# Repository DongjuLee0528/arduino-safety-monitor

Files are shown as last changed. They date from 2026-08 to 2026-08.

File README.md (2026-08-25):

# Invent the Future with Arduino UNO Q and App Lab: Mobile Safety Monitoring Robot

A mobile Arduino UNO Q robot that combines autonomous obstacle avoidance with App Lab helmet-compliance monitoring.

## Project Overview

This project was built for the "Invent the Future with Arduino UNO Q and App Lab" competition. It explores a mobile safety-monitoring robot that can patrol a workspace, avoid nearby obstacles, detect people with a camera, classify whether a detected person is wearing a safety helmet, and show the system state in an Arduino App Lab dashboard.

The repository contains Arduino MCU firmware, a Python MPU runtime, an App Lab dashboard package generator, AI training and evaluation code, model artifacts, tests, wiring documentation, robot photographs, and demonstration media.

This is an independently developed project. Hardware details that have not yet been confirmed are marked instead of being guessed.

## Problem Statement

Fixed safety cameras only observe selected areas. A mobile robot can inspect additional viewpoints while carrying its own camera, obstacle sensors, and local control logic. This prototype combines autonomous navigation with helmet-compliance monitoring.

This project is a functional prototype and is not an industrially certified safety device.

## Project Goals

- Build a physical Arduino UNO Q robot platform.
- Keep MCU responsibilities focused on motor control, ultrasonic sensing, motion authorization, and local warning outputs.
- Keep MPU responsibilities focused on camera input, AI inference, dashboard state, App Lab integration, and alert transmission.
- Use Arduino App Lab Bridge IPC for MCU-MPU commands.
- Detect people, crop each person, and classify helmet status.
- Provide clear dashboard evidence for helmet and no-helmet states.
- Stop or restrict motion on communication loss, stale motion lease, manual-hold timeout, and explicit reset.

## Key Features

| Feature | Evidence | Status |
|---|---|---|
| App Lab Bridge RPC communication | `mpu/bridge_rpc.py`, `arduino/arduino.ino`, `arduino/comm.h` | Implemented in code |
| MCU motor control through L298N | `arduino/motor.h`, `arduino/pins.h` | Implemented in firmware |
| Four HC-SR04 ultrasonic sensors | `arduino/ultrasonic.h`, `arduino/pins.h` | Implemented in firmware |
| Autonomous obstacle-avoidance state machine | `arduino/navigation.h`, `arduino/robot_controller.h` | Implemented and demonstrated separately |
| Helmet/no-helmet AI pipeline | `mpu/main.py`, `mpu/detector.py`, `mpu/classifier.py` | Implemented in Python runtime |
| App Lab dashboard | `app_lab/ui/assets/index.html`, `app_lab/generate_app_lab.py` | Implemented and packaged |
| Dashboard statistics and event log | `mpu/dashboard_state.py`, dashboard screenshots | Implemented in software |
| LED warning output on D3 | `arduino/pins.h`, `arduino/comm.h` | Implemented in firmware |
| Buzzer diagnostic output on D13 | `arduino/pins.h`, `arduino/comm.h` | Implemented in firmware |

## Innovation and Differentiation

The project combines mobile monitoring and personal protective equipment detection in one small prototype. Instead of relying only on fixed cameras, the robot can move through a space while the MPU performs person detection and helmet classification.

The MCU remains responsible for time-sensitive motion, sensor processing, and safety behaviour, while the MPU handles AI inference, dashboard state, camera processing, and alert logic.

The communication design separates general connectivity from motion authorization. A connectivity check alone does not authorize continued movement. Motion authority is maintained through control and manual-hold updates, reducing the risk of stale commands continuing after communication problems.

## System Architecture

```mermaid
flowchart LR
    Camera[USB camera] --> MPU[Python MPU runtime]
    MPU --> Detector[MobileNet SSD person detector]
    Detector --> Crop[Person crop]
    Crop --> Classifier[ONNX helmet classifier]
    Classifier --> Dashboard[App Lab dashboard state]
    Classifier --> Alert[Alert manager and HTTP sender]
    Dashboard --> AppUI[App Lab Web UI]
    AppUI --> Bridge[Arduino App Lab Bridge.call]
    MPU --> Bridge
    Bridge --> MCU[Arduino UNO Q MCU firmware]
    MCU --> Nav[Navigation manager]
    MCU --> Motors[L298N motor driver and TT motors]
    Sensors[HC-SR04 ultrasonic sensors] --> MCU
    MCU --> LocalAlert[D3 LED and D13 buzzer outputs]
```

The active MCU-MPU communication path is Arduino UNO Q App Lab Bridge IPC using named RPC endpoints such as:

- `asm_motor`
- `asm_mode`
- `asm_status`
- `asm_safe_reset`

The current implementation does not use raw USB Serial JSON-RPC as its production transport.

## End-to-End Operation Flow

1. The App Lab package starts the Python adapter generated by `app_lab/generate_app_lab.py`.
2. The adapter validates the runtime model files and starts `HelmetDetectionSystem`.
3. The Python runtime opens the camera and connects to the MCU through `Bridge.call`.
4. Each camera frame is processed by `PersonDetector`.
5. Each detected person is cropped and passed to `HelmetClassifier`.
6. The dashboard state is updated with worker presence, helmet result, confidence, statistics, and recent events.
7. For a no-helmet incident, the alert manager can request the MCU warning output and send an HTTP alert.
8. The dashboard polls `/api/state` and `/api/frame` to display the live system state and camera frame.
9. The MCU executes autonomous or manual motor behaviour and reports status through `asm_status`.
10. `safe_reset`, motion lease timeout, manual-hold timeout, and communication timeout stop or restrict movement.

## Implementation Status

| Area | Status | Notes |
|---|---|---|
| Physical robot | Built | Supported by robot photographs |
| Circuit diagram | Documented | `docs/images/circuit-image.svg` |
| MCU firmware | Implemented | Arduino RouterBridge/RPClite endpoints are registered |
| Python MPU runtime | Implemented | Integrates the camera, detector, classifier, Bridge, sender, and dashboard |
| App Lab dashboard | Implemented | HTML/CSS/JavaScript dashboard and generated package included |
| Autonomous navigation | Implemented | Demonstrated in a separate video |
| Helmet dashboard state | Implemented | Demonstrated through dashboard screenshots |
| LED and buzzer outputs | Firmware implemented | Physical verification evidence is limited |
| Continuous end-to-end demonstration | Not documented | Navigation and helmet monitoring were demonstrated separately |

## Hardware Overview

The robot uses a four-wheel chassis with an Arduino UNO Q, L298N motor driver, four TT geared motors, four HC-SR04 ultrasonic sensors, a Logitech C922 Pro HD Stream Webcam, and custom 3D-printed mechanical parts.

The power system uses a TERANTY 2S LiPo battery, an XL6009 DC-DC boost converter configured to 18 V, an Aideepen USB-C PD output module, and a DSEOM USB-C 7-in-1 multi-hub.

The Arduino UNO Q and Logitech C922 camera are connected through the USB-C hub.

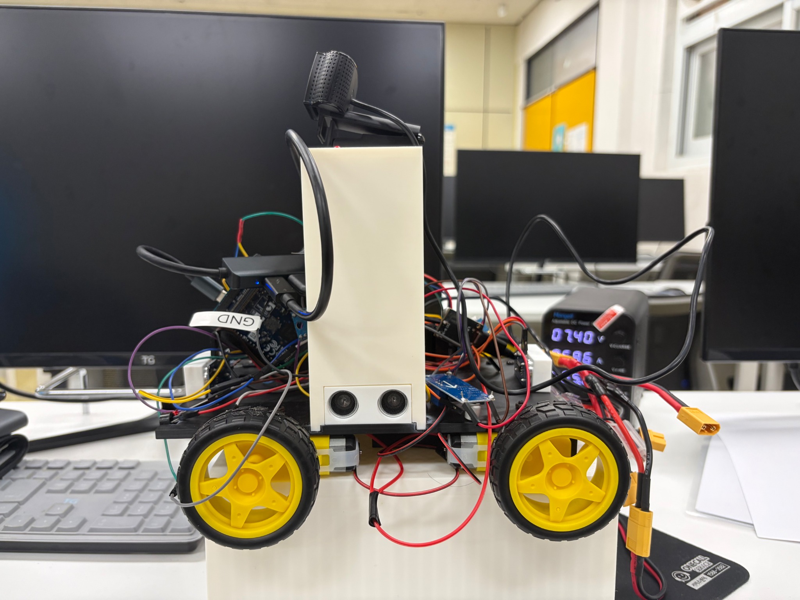
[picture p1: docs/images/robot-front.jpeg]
Front view of the completed robot


The front photograph shows the completed robot with the front ultrasonic sensor assembly and upper electronics area.

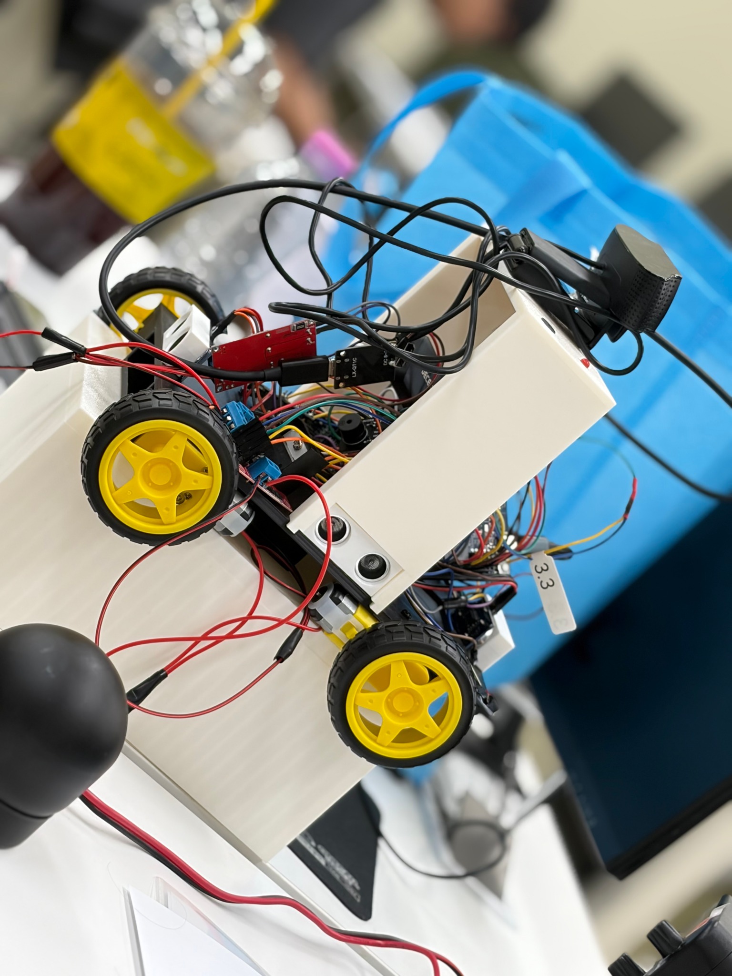
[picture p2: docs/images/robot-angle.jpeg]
Angled view of the completed robot


The angled photograph shows the chassis, wheels, wiring, controller area, and camera mount.

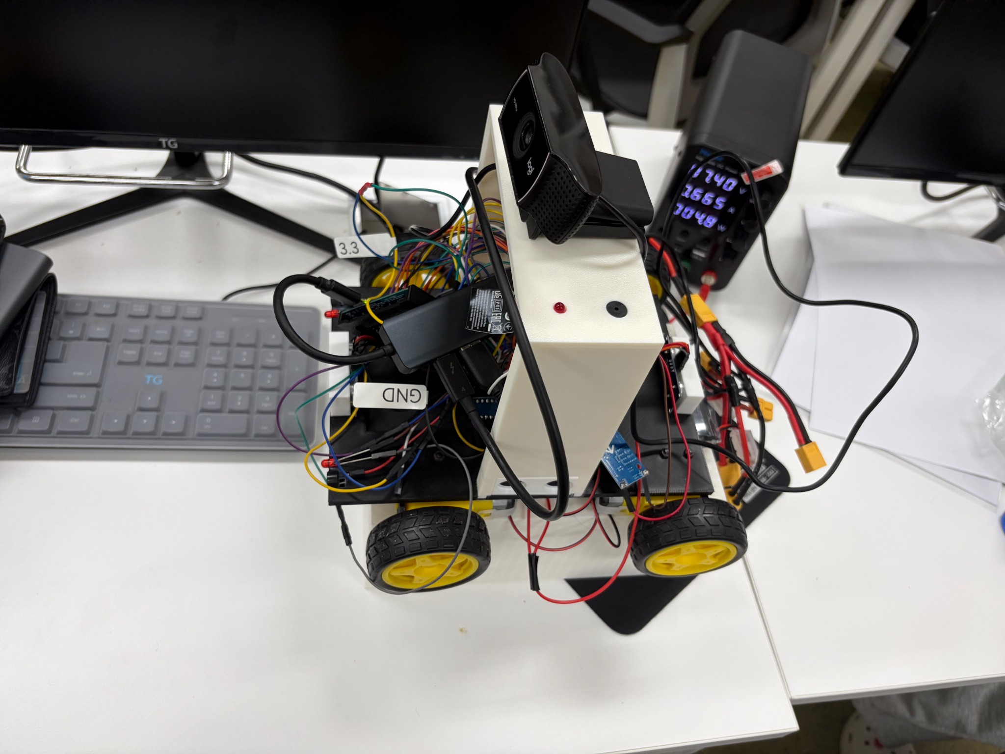
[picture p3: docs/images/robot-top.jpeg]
Top view of the completed robot


The top photograph shows the controller and wiring arrangement.

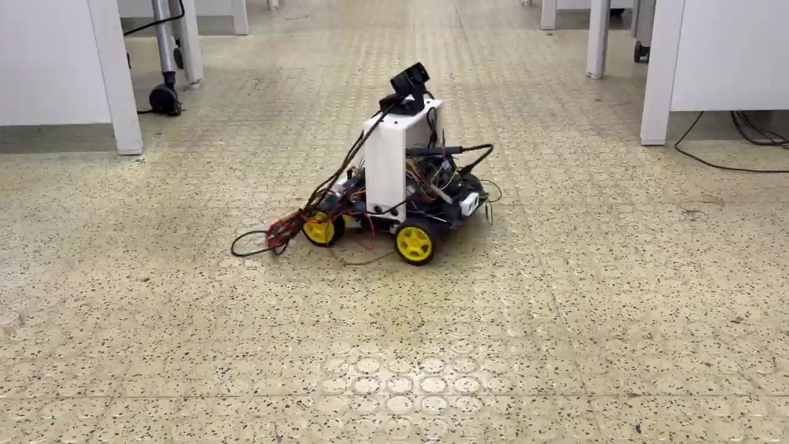
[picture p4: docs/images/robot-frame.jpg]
Robot frame before final assembly


The frame photograph shows the custom base structure before the final upper assembly was installed.

## Complete Hardware BOM

| Component | Model or Specification | Quantity | Purpose | Status |
|---|---|---:|---|---|
| Controller board | Arduino UNO Q | 1 | MCU firmware, App Lab Bridge, and robot control | Implemented |
| Motor driver | L298N dual H-bridge | 1 | Controls the left and right motor groups | Implemented |
| DC geared motors | TT geared motor | 4 | Four-wheel drive | Implemented |
| Wheels | TT motor-compatible wheel | 4 | Robot locomotion | Implemented |
| Ultrasonic sensors | HC-SR04 | 4 | Front, rear, left, and right obstacle sensing | Implemented |
| Camera | Logitech C922 Pro HD Stream Webcam | 1 | Person detection and helmet classification | Implemented |
| Logic-level shifter | TXS0108E | 1 | 5 V and 3.3 V logic-level conversion | Implemented |
| Battery | TERANTY 2S LiPo, 7.4 V nominal, 2,200 mAh, 50C, XT60 | 1 | Main robot power source | Implemented |
| Boost converter | XL6009 adjustable DC-DC boost converter | 1 | Raises the battery voltage to 18 V | Implemented |
| USB-C PD output module | Aideepen 45 W model, DC 8–30 V input, PD/QC3.0/SCP/PPS | 1 | Generates USB-C PD output from the boosted supply | Implemented |
| USB-C multiport hub | DSEOM USB-C 7-in-1 multi-hub | 1 | Connects and powers the Arduino UNO Q and USB camera | Implemented |
| Alert LED | Red LED connected to D3 | 1 | Local visual warning | Firmware implemented |
| Buzzer | Buzzer connected to D13 | 1 | Local audible warning or diagnostic output | Firmware implemented |
| Jumper wires and connectors | Signal and power wiring | 1 set | Electrical connections | Implemented |
| M3 × 8 mm bolts | M3, 8 mm length | 8 | Component and bracket fastening | Implemented |
| M3 × 25 mm bolts | M3, 25 mm length | 8 | Chassis and structural fastening | Implemented |
| M3 nuts | Standard M3 nuts | 16 | Fastens the M3 bolts | Implemented |
| Custom 3D-printed parts | Chassis, base plate, sensor mounts, camera mount, and electronics mounts | 1 set | Mechanical structure and component mounting | Designed by Dongju Lee |
| TT motor brackets | [TT Gear Motor Mount](https://makerworld.com/en/models/519327-tt-gear-motor-mount) by [Chief human](https://makerworld.com/en/@Chief_human) | 4 | Mounts the four TT motors | Used with creator permission and licensed under [CC BY 4.0](https://creativecommons.org/licenses/by/4.0/) |

## Software and Development Tools

| Tool or Library | Evidence | Purpose |
|---|---|---|
| Arduino and C++ | `arduino/*.ino`, `arduino/*.h` | MCU firmware |
| Arduino App Lab | `app_lab/generate_app_lab.py`, generated App Lab package | Packaging and dashboard runtime |
| Python | `mpu/*.py`, `mpu/ai/*.py` | MPU runtime, AI training, and tests |
| JavaScript, HTML, and CSS | `app_lab/ui/assets/index.html` | Dashboard UI |
| OpenCV | `requirements.txt`, `mpu/camera.py`, `mpu/detector.py` | Camera capture and image processing |
| ONNX Runtime | `requirements.txt`, `mpu/detector.py`, `mpu/classifier.py` | Runtime AI inference |
| PyTorch and torchvision | `requirements.txt`, `mpu/ai/train.py` | AI model training |
| ONNX | `requirements.txt`, `mpu/ai/convert.py` | Model conversion and validation |
| Pillow | `requirements.txt`, `mpu/classifier.py` | Image preprocessing |
| requests | `requirements.txt`, `mpu/sender.py` | HTTP alert transmission |
| unittest and pytest-compatible tests | `mpu/tests/`, `tests/`, `setup.cfg` | Automated software testing |
| 3D modelling tools | `models/*.stl`, `models/*.3mf` | Mechanical design assets |

## Circuit Diagram and Power Architecture

Circuit diagram for the Arduino UNO Q safety monitoring robot

The circuit diagram documents the Arduino UNO Q, L298N motor driver, four HC-SR04 sensors, D3 LED output, and D13 buzzer output.

The verified system power flow is:

```text
TERANTY 2S LiPo Battery
7.4 V nominal / 2,200 mAh / 50C / XT60
              |
              v
XL6009 DC-DC Boost Converter
Output configured to 18 V
              |
              v
Aideepen 45 W USB-C PD Output Module
              |
              v
DSEOM USB-C 7-in-1 Multi-hub
              |
              +-- Arduino UNO Q
              |
              `-- Logitech C922 Pro HD Stream Webcam
```

The XL6009 is used only as a DC-DC boost converter. USB Power Delivery output is handled by the separate Aideepen USB-C PD module.

The 18 V value applies to the XL6009 output supplied to the USB-C PD module. It does not mean that every downstream device directly receives 18 V. The USB-C PD module and connected devices negotiate or regulate their downstream voltage.

The Aideepen module supports up to 45 W, but this does not mean that the complete system continuously supplies 45 W. Actual available power is limited by the XL6009 converter, battery voltage, wiring, thermal conditions, and negotiated USB-C PD profile.

### Electrical Notes

- L298N ENA and ENB are driven by PWM pins D5 and D6.
- L298N direction pins use D2, D4, D7, and D8.
- Four HC-SR04 sensors use D9/D10, D11/D12, A0/A1, and A2/A3.
- The Arduino UNO Q, L298N, battery circuit, and sensors must use a common ground.
- HC-SR04 sensors are powered through the 5 V bus.
- The XL6009 output must be measured before downstream devices are connected.

### Software Safety Behaviour

- The MCU stops motion when the motion lease expires.
- The MCU switches to manual mode and queues a stop when `safe_reset` is executed.
- Missing or stale ultrasonic readings are treated as blocked.
- Manual movement requires continuing hold or lease refreshes.
- Communication loss prevents stale motion commands from continuing indefinitely.

## Pin Map

| Function | Arduino Pin | Firmware Constant |
|---|---|---|
| L298N ENA, left PWM | D5 | `MOTOR_LEFT_ENABLE_PIN` |
| L298N IN1, left direction A | D2 | `MOTOR_LEFT_IN1_PIN` |
| L298N IN2, left direction B | D4 | `MOTOR_LEFT_IN2_PIN` |
| L298N ENB, right PWM | D6 | `MOTOR_RIGHT_ENABLE_PIN` |
| L298N IN3, right direction A | D7 | `MOTOR_RIGHT_IN1_PIN` |
| L298N IN4, right direction B | D8 | `MOTOR_RIGHT_IN2_PIN` |
| Alert LED | D3 | `ALERT_LED_PIN` |
| Buzzer diagnostic output | D13 | `BUZZER_DIAG_PIN` |
| Front HC-SR04 trigger | D9 | `ULTRASONIC_FRONT_TRIGGER_PIN` |
| Front HC-SR04 echo | D10 | `ULTRASONIC_FRONT_ECHO_PIN` |
| Rear HC-SR04 trigger | D11 | `ULTRASONIC_REAR_TRIGGER_PIN` |
| Rear HC-SR04 echo | D12 | `ULTRASONIC_REAR_ECHO_PIN` |
| Left HC-SR04 trigger | A0 | `ULTRASONIC_LEFT_TRIGGER_PIN` |
| Left HC-SR04 echo | A1 | `ULTRASONIC_LEFT_ECHO_PIN` |
| Right HC-SR04 trigger | A2 | `ULTRASONIC_RIGHT_TRIGGER_PIN` |
| Right HC-SR04 echo | A3 | `ULTRASONIC_RIGHT_ECHO_PIN` |

The following pins are reserved by `arduino/pins.h`:

| Pin | Purpose |
|---|---|
| D0 | UART RX |
| D1 | UART TX |
| A4 | I2C SDA |
| A5 | I2C SCL |

## Hardware Assembly Guide

1. Print or prepare the custom chassis components from the files in `models/`.
2. Print four TT motor brackets using the credited third-party model.
3. Mount the four TT geared motors using the TT motor brackets.
4. Attach the four wheels to the motors.
5. Assemble the structural components using the M3 bolts and nuts.
6. Mount the Arduino UNO Q and L298N motor driver.
7. Install the four HC-SR04 sensors for front, rear, left, and right coverage.
8. Mount the Logitech C922 camera.
9. Wire the L298N motor driver according to the pin map.
10. Connect the TERANTY 2S LiPo battery to the XL6009 input.
11. Disconnect the Arduino UNO Q, USB-C hub, camera, and PD module before adjusting the XL6009.
12. Adjust the XL6009 output and confirm 18 V using a multimeter.
13. Connect the XL6009 output to the Aideepen USB-C PD module.
14. Connect the Aideepen module to the DSEOM multi-hub PD input.
15. Connect the Arduino UNO Q and Logitech C922 camera to the DSEOM hub.
16. Verify polarity, common ground, converter output, and motor/logic power separation.
17. Connect power only after completing all electrical checks.

Do not execute motor or diagnostic commands until the robot is physically supported, the wheels are clear, and the power wiring has been checked.

## AI Pipeline

The runtime AI flow is:

1. `CameraCapture` captures a BGR frame from camera index `0`.
2. `PersonDetector` loads `mpu/ai/models/ssd_mobilenet_v1_12.onnx`.
3. The detector filters COCO class ID `1` for person detections with a confidence of at least `0.5`.
4. `HelmetDetectionSystem.crop_person()` crops each detected person.
5. `HelmetClassifier` loads `mpu/ai/models/best_model.onnx`.
6. The classifier resizes each crop to `224 × 224`.
7. ImageNet normalization is applied.
8. ONNX Runtime performs helmet classification.
9. Output index `0` represents `no_helmet`.
10. Output index `1` represents `helmet`.
11. The runtime predicts `helmet` only when `P(helmet) >= 0.83`.
12. The dashboard receives the result, confidence, bounding box, statistics, and event updates.

The training loader uses per-object crops from annotated source images. This matches the runtime classifier input more closely than full-frame training.

## Datasets and Data Preparation

The training code uses the SHEL5K dataset path configured in `mpu/config.py`:

```text
~/AIdatasets/helmet-safety-robot/raw/9rcv8mm682-4/Safety Helmet Wearing Dataset
```

The expected dataset structure is:

```text
Safety Helmet Wearing Dataset/
+-- Annotations/
`-- Images/
```

The following Pascal VOC object labels are used:

| Annotation Label | Class Index | Runtime Class |
|---|---:|---|
| `person_no_helmet` | 0 | `no_helmet` |
| `person_with_helmet` | 1 | `helmet` |

Head-only and helmet-only labels are excluded because they do not match the runtime whole-person crop contract.

SHWD is present in configuration as `SHWD_PATH`, but it is excluded from the current baseline training process.

## Training Process

Run the training process with:

```bash
python -m mpu.ai.train \
  --architecture efficientnet_b0 \
  --epochs 30 \
  --batch-size 32 \
  --lr 0.001 \
  --seed 42 \
  --patience 5 \
  --train-ratio 0.8 \
  --output-dir mpu/ai/runs
```

Training artifacts are written under:

```text
mpu/ai/runs/<run_id>/
```

The training script protects production model files in `mpu/ai/models/` from being overwritten.

Supported classifier architectures:

- EfficientNet-B0
- MobileNetV3-Small
- MobileNetV3-Large

Training uses:

- ImageNet pretrained weights
- Adam optimizer
- Weighted `CrossEntropyLoss`
- Source-image-grouped train/validation splitting
- Early stopping based on validation loss
- Fixed random seed for reproducibility

## Model Comparison and Selection

The repository includes comparison artifacts under:

```text
mpu/ai/comparisons/four_model_comparison/
```

The selected production candidate is:

```text
20260820_204342_efficientnet_b0
```

This model uses EfficientNet-B0 with a learning rate of `0.0003`.

| Run | Architecture | Learning Rate | Validation Accuracy | Macro F1 | No-Helmet Recall | Missed Violations | False Alarms | ONNX Size |
|---|---|---:|---:|---:|---:|---:|---:|---:|
| `20260820_171048_efficientnet_b0` | EfficientNet-B0 | 0.001 | 93.6136% | 0.9177 | 0.9342 | 50 | 146 | 15.978 MB |
| `20260820_193048_mobilenet_v3_small` | MobileNetV3-Small | 0.001 | 93.7113% | 0.9170 | 0.8987 | 77 | 116 | 6.157 MB |
| `20260820_204342_efficientnet_b0` | EfficientNet-B0 | 0.0003 | 94.8843% | 0.9330 | 0.9342 | 50 | 107 | 15.978 MB |
| `20260820_210239_mobilenet_v3_large` | MobileNetV3-Large | 0.001 | 92.7990% | 0.9076 | 0.9250 | 57 | 164 | 16.399 MB |

These values are validation-set metrics from repository artifacts. They do not prove real-world industrial performance.

## Model Evaluation and Threshold Selection

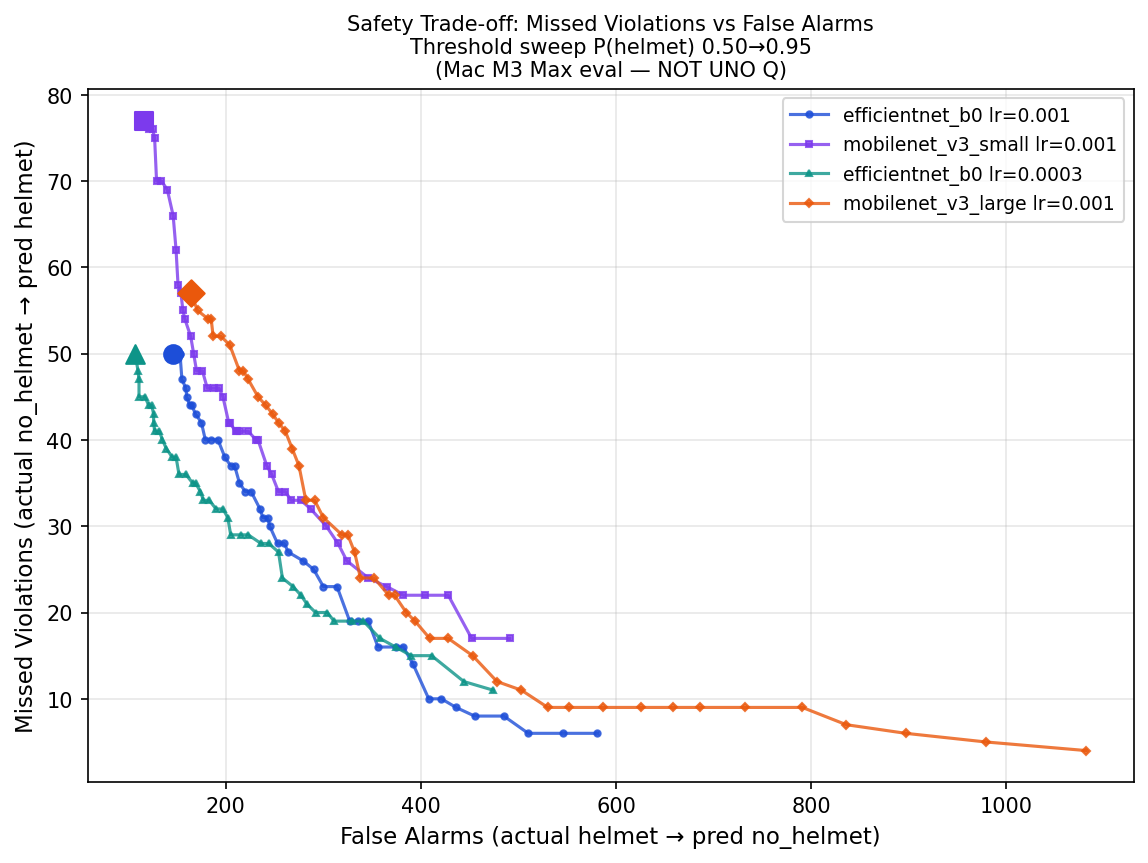
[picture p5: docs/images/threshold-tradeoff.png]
Threshold trade-off chart


The threshold graph compares missed violations and false alarms for `P(helmet)` thresholds from `0.50` to `0.95`.

The evaluation was performed on a MacBook Pro with an M3 Max. It is not an Arduino UNO Q inference-latency benchmark.

The runtime threshold is configured in `mpu/config.py`:

```python
HELMET_ACCEPTANCE_THRESHOLD = 0.83
```

For `20260820_204342_efficientnet_b0`, the threshold sweep records:

- Threshold: `0.83`
- No-helmet recall: at least `97%`
- Missed violations: `22`
- False alarms: `277`
- Evaluation samples: `3,069`
- PyTorch/ONNX decision disagreements: `0`

## Installation

Clone the repository:

```bash
git clone https://github.com/DongjuLee0528/arduino-safety-monitor.git
cd arduino-safety-monitor
```

Create and activate a Python virtual environment:

```bash
python -m venv .venv
source .venv/bin/activate
```

Install the required packages:

```bash
python -m pip install -r requirements.txt
```

Generate the Arduino App Lab package:

```bash
python app_lab/generate_app_lab.py
```

This creates or refreshes:

```text
app_lab/Arduino Safety Monitor/
```

The package is generated from the authoritative `mpu/`, `arduino/`, and `app_lab/ui/assets/` sources.

## Configuration

| File | Purpose |
|---|---|
| `arduino/config.h` | Motor speeds, sensor thresholds, timing, motion lease, command timeout, and buzzer timing |
| `arduino/pins.h` | MCU pin assignments |
| `mpu/config.py` | Dataset paths, model paths, camera settings, thresholds, server URL, and App Lab development mode |
| `app_lab/requirements_app_lab.txt` | App Lab Python runtime dependencies |
| `app_lab/Arduino Safety Monitor/app.yaml` | Generated App Lab application configuration |
| `app_lab/Arduino Safety Monitor/sketch/sketch.yaml` | Generated sketch profile |

The following runtime model files are required:

```text
mpu/ai/models/ssd_mobilenet_v1_12.onnx
mpu/ai/models/best_model.onnx
mpu/ai/models/best_model.onnx.data
```

`best_model.pth` is a training artifact and is not required for runtime inference.

Hardware-free development mode can be enabled with:

```bash
APP_LAB_DEV_MODE=true python -m mpu.main
```

Production mode is used when `APP_LAB_DEV_MODE` is not set.

## Hardware Prerequisites

- Arduino UNO Q
- L298N motor driver
- Four TT geared motors
- Four HC-SR04 ultrasonic sensors
- Logitech C922 Pro HD Stream Webcam
- TERANTY 2S LiPo battery
- XL6009 boost converter configured to 18 V
- Aideepen 45 W USB-C PD output module
- DSEOM USB-C 7-in-1 multi-hub
- Required wiring and mechanical components

## Running the System

### Arduino App Lab Package

1. Generate the package:

   ```bash
   python app_lab/generate_app_lab.py
   ```

2. Open or deploy `app_lab/Arduino Safety Monitor/` in Arduino App Lab.
3. Confirm that the generated package includes:

   ```text
   python/main.py
   python/mpu/
   assets/index.html
   sketch/sketch.ino
   sketch/sketch.yaml
   ```

4. Connect the robot hardware according to the circuit diagram and pin map.
5. Start the App Lab application.
6. Confirm that the dashboard displays connection, camera, detection, mode, movement, and safety-state fields.
7. Use Stop, Reset, or Emergency Stop before disconnecting power.

### Local Python Runtime

```bash
python -m mpu.main
```

This command requires the camera, runtime model files, and App Lab Bridge unless `APP_LAB_DEV_MODE=true` is configured.

## Testing and Verification

Run the software tests with:

```bash
python -m unittest discover -s mpu/tests -p 'test*.py'
python -m unittest discover -s tests -p 'test*.py'
```

The App Lab packaging tests may regenerate the App Lab package directory.

| Verification Item | Method | Expected Result | Recorded Result | Status |
|---|---|---|---|---|
| Bridge RPC endpoint mapping | `mpu/tests/test_bridge_rpc.py` | Python commands map to `asm_*` endpoints | Mapping and ACK validation covered | Automated software test |
| Command validation | `mpu/tests/test_bridge_rpc.py` | Invalid commands are rejected | Invalid inputs covered | Automated software test |
| Safe reset mapping | `mpu/tests/test_bridge_rpc.py` | Calls `asm_safe_reset` and validates the ACK | Mapping covered | Automated software test |
| Dashboard connection state | `mpu/tests/test_main_integration.py` | Connection state is updated | Mocked integration covered | Automated software test |
| Helmet dashboard state | Integration test and screenshot | Helmet state appears on the dashboard | Screenshot included | Software and demonstration evidence |
| No-helmet dashboard state | Integration test and screenshot | No-helmet warning appears | Screenshot included | Software and demonstration evidence |
| Daily statistics | `mpu/tests/test_daily_statistics.py` | Statistics update by UTC day | Test included | Automated software test |
| Event logging | `mpu/tests/test_event_logging.py` | Events are recorded | Test included | Automated software test |
| App Lab packaging | `tests/test_app_lab_packaging.py` | Generated package matches authoritative sources | Test included | Automated software test |
| Autonomous navigation | `docs/images/autonomous-driving.mp4` | Robot performs autonomous movement | Video included | Physical demonstration |
| Motor and ultrasonic operation | Firmware and navigation video | Robot moves and reacts to obstacles | Demonstrated by video | Physical evidence |
| LED and buzzer hardware | Firmware | Warning outputs activate | No stored hardware verification log | Firmware only |

## Demonstrations

The autonomous-driving video and helmet-detection screenshots are separate demonstrations. They are not presented as one continuous end-to-end recording.

### Autonomous Navigation

[Watch the autonomous-driving demonstration](docs/images/autonomous-driving.mp4)

The video demonstrates autonomous navigation.

### Helmet Detected

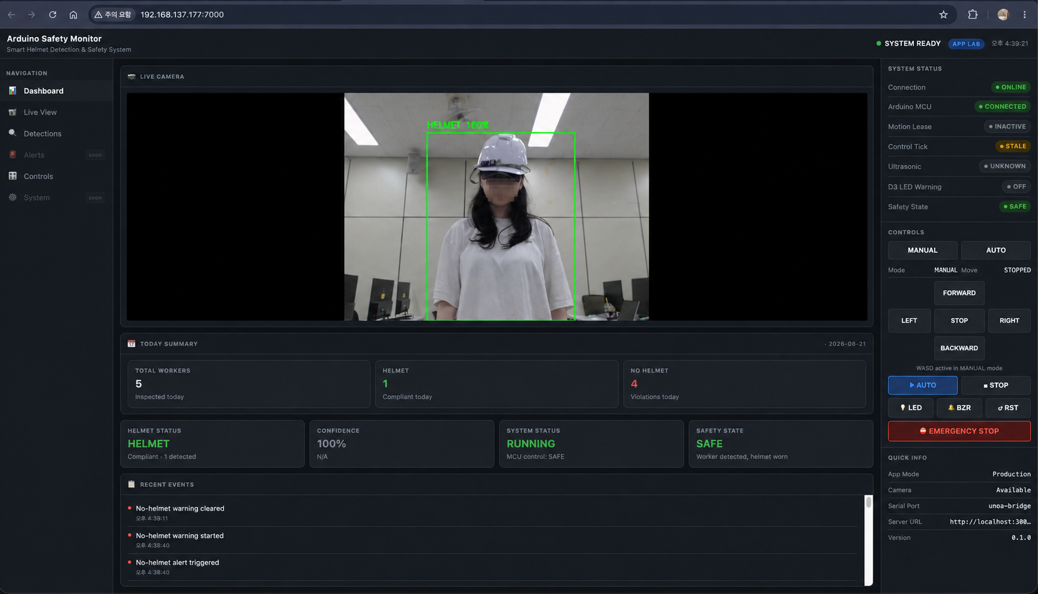
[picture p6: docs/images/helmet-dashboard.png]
Dashboard state with helmet detected


The helmet dashboard screenshot shows:

- Green person bounding box
- `HELMET` classification
- Safe status
- Helmet compliance count
- Recent dashboard events

### No Helmet Detected

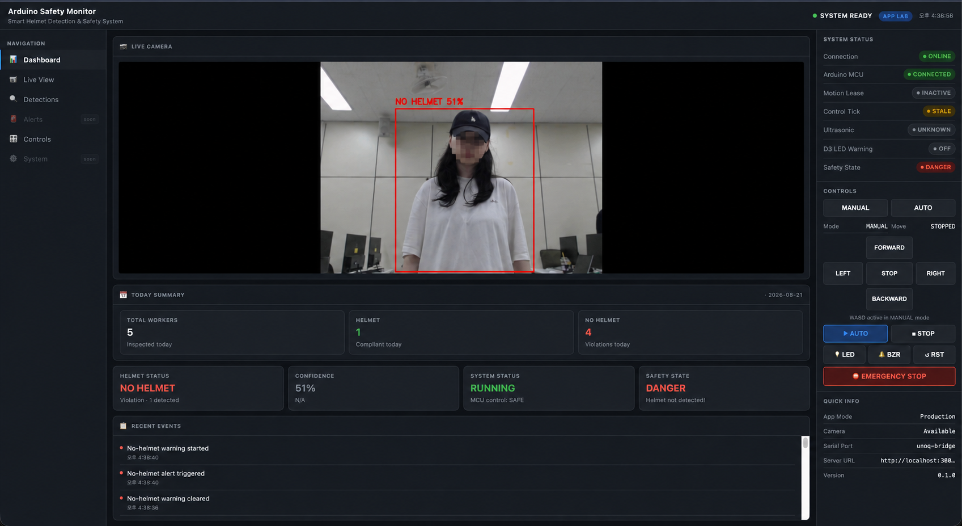
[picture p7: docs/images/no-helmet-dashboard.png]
Dashboard state with no helmet detected


The no-helmet dashboard screenshot shows:

- Red person bounding box
- `NO HELMET` classification
- Danger status
- No-helmet incident count
- Recent warning events

## Troubleshooting

| Symptom | Likely Cause | Check |
|---|---|---|
| `Model files missing` | Required ONNX files are absent | Confirm the runtime models exist under `mpu/ai/models/` |
| Camera unavailable | Camera is disconnected or development mode is active | Check the USB camera and `APP_LAB_DEV_MODE` |
| Dashboard shows hardware unavailable | Bridge connection failed | Confirm that the App Lab Bridge and MCU sketch are running |
| Motor command rejected in AUTO mode | Manual movement is blocked in AUTO mode | Switch to MANUAL mode |
| Manual movement stops quickly | Manual hold or motion lease expired | Continue refreshing the manual control input |
| Robot stops after communication loss | Expected safety behaviour | Reconnect and issue a valid command |
| Ultrasonic state is unknown | No fresh distance readings | Check HC-SR04 wiring and sensor orientation |
| LED or buzzer does not activate | Hardware wiring is not verified | Check D3, D13, resistor or module requirements, and common ground |
| UNO Q or camera restarts | Power voltage drops under load | Measure XL6009 output under load and check module temperature |
| No USB-C PD output | PD negotiation or power connection failed | Check the Aideepen module, USB-C cable, and hub PD input |

## Project Structure

```text
.
+-- README.md
+-- AGENTS.md
+-- requirements.txt
+-- setup.cfg
+-- arduino/
+-- app_lab/
+-- docs/
|   `-- images/
+-- models/
+-- mpu/
+-- tests/
`-- png/
```

Important paths:

| Path | Purpose |
|---|---|
| `arduino/arduino.ino` | MCU sketch entry point and RPC registration |
| `arduino/comm.h` | MCU command state, ACK/error responses, warning outputs, and safety state |
| `arduino/robot_controller.h` | Top-level MCU motion orchestration |
| `mpu/main.py` | Camera, AI, Bridge, sender, and dashboard integration |
| `mpu/bridge_rpc.py` | Python-side Arduino App Lab Bridge RPC client |
| `mpu/ai/train.py` | Helmet classifier training |
| `mpu/ai/convert.py` | PyTorch-to-ONNX conversion |
| `app_lab/generate_app_lab.py` | Arduino App Lab package generator |
| `app_lab/ui/assets/index.html` | Dashboard user interface |
| `models/` | Original and third-party 3D model files |
| `tests/test_app_lab_packaging.py` | Package generator tests |

## 3D Model Files

```text
models/
+-- arduino-uno-q-4wd-robot.3mf
+-- arduino-uno-q-4wd-robot.stl
+-- robot-base-plate.3mf
`-- TT+Gear+Motor+Mount.3mf
```

The following files were created by Dongju Lee:

- `models/arduino-uno-q-4wd-robot.3mf`
- `models/arduino-uno-q-4wd-robot.stl`
- `models/robot-base-plate.3mf`

The following file is a separately licensed third-party model:

- `models/TT+Gear+Motor+Mount.3mf`

The TT motor bracket was not designed by Dongju Lee. Its creator and licence are documented in the Credits and License sections.

## Development Challenges and Solutions

| Challenge | Solution |
|---|---|
| Avoiding contradictory MCU-MPU transports | The current implementation uses Arduino App Lab Bridge/RPClite endpoints instead of raw USB Serial JSON-RPC |
| Maintaining motion safety if host updates stop | Firmware uses a motion lease, manual-hold timeout, communication freshness, and `safe_reset` |
| Preventing stale ultrasonic readings from being treated as clear space | The navigation manager treats unavailable readings as blocked |
| Matching classifier training with runtime input | The dataset loader trains on person crops from Pascal VOC object boxes |
| Reducing missed no-helmet detections | A threshold sweep records the trade-off between missed violations and false alarms |
| Packaging App Lab without duplicating source code | The package generator copies authoritative firmware, runtime, and UI sources |
| Testing without physical hardware | Tests mock the camera, Bridge, sender, detector, and classifier |
| Supplying USB-C PD power from a 2S battery | The XL6009 raises the battery voltage to 18 V before the USB-C PD module |
| Building a custom robot structure | The chassis and component mounts were modelled and 3D printed for the project |

## Known Limitations

- The autonomous-navigation video and dashboard screenshots were recorded separately.
- A single continuous end-to-end demonstration is not currently included.
- Physical LED and buzzer operation does not have a stored verification log.
- The complete power chain has not been documented as continuously supplying 45 W.
- Dataset validation metrics do not prove real-world industrial performance.
- Mac M3 Max evaluation results are not Arduino UNO Q latency measurements.
- The default HTTP alert server implementation is not included.
- This prototype is not an industrially certified safety device.

## Electrical Safety Notes

- Disconnect the Arduino UNO Q, camera, hub, and PD module before adjusting the XL6009.
- Confirm the XL6009 output using a multimeter before connecting downstream devices.
- Measure the converter output under load, not only without a load.
- Avoid short circuits and reverse polarity.
- Use a charger designed specifically for a 2S LiPo battery.
- Do not overcharge, over-discharge, puncture, crush, or otherwise damage the LiPo battery.
- Do not adjust the converter while sensitive devices are connected.
- Stop operation if the XL6009, PD module, wiring, or battery becomes abnormally hot.

## Future Improvements

- Record a continuous end-to-end demonstration.
- Create a hardware verification log for motors, sensors, LED, buzzer, power, and shutdown behaviour.
- Measure loaded voltage, current, temperature, and runtime for the complete power chain.
- Profile ONNX inference latency on the Arduino UNO Q MPU environment.
- Add a documented receiver for remote HTTP alerts.
- Expand classification to additional PPE classes after collecting appropriate datasets.
- Add detailed step-by-step wiring photographs and assembly drawings.

## Project Author and Mechanical Design

This project was independently designed and developed by **Dongju Lee**.

The independently completed work includes:

- Project concept and system design
- Hardware integration
- Mechanical assembly
- Custom 3D modelling
- Arduino firmware
- Python runtime
- AI training and inference pipeline
- Arduino App Lab dashboard
- Testing
- Documentation

All custom mechanical parts used in this project—including the robot chassis, base plate, ultrasonic sensor mounts, camera mount, and electronic component mounts—were modelled by Dongju Lee, except for the TT motor brackets.

The TT motor brackets use the external **[TT Gear Motor Mount](https://makerworld.com/en/models/519327-tt-gear-motor-mount)** model created by **[Chief human](https://makerworld.com/en/@Chief_human)**.

The model is published under the **[Creative Commons Attribution 4.0 International license](https://creativecommons.org/licenses/by/4.0/)**.

The creator also provided direct written permission to use and modify the model for this project and requested attribution through the MakerWorld model link.

This project does not claim ownership of the original TT motor bracket design. No modification to the original bracket geometry is documented in this repository.

## Credits and Third-Party Assets

| Asset or Dependency | Repository Evidence | License or Credit Status |
|---|---|---|
| MobileNet SSD ONNX person detector | `mpu/ai/models/ssd_mobilenet_v1_12.onnx` | Subject to its original source and licence |
| SHEL5K safety helmet dataset | `mpu/config.py`, `mpu/ai/dataset/loader.py` | Subject to the dataset provider's terms |
| PyTorch and torchvision pretrained weights | `mpu/ai/train.py` | Subject to the applicable upstream licences |
| Python libraries | `requirements.txt`, `app_lab/requirements_app_lab.txt` | Subject to each package licence |
| Original CAD and 3D model files | `models/*.stl`, `models/*.3mf`, excluding `TT+Gear+Motor+Mount.3mf` | Created by Dongju Lee; all rights reserved |
| TT motor bracket model | [TT Gear Motor Mount](https://makerworld.com/en/models/519327-tt-gear-motor-mount) by [Chief human](https://makerworld.com/en/@Chief_human) | Licensed separately under [CC BY 4.0](https://creativecommons.org/licenses/by/4.0/); direct use and modification permission also received |
| Robot photographs, dashboard screenshots, circuit diagram, and demonstration video | `docs/images/` | Created by Dongju Lee; all rights reserved |

The TT motor bracket attribution and licence notice must be preserved when the model or a modified version is redistributed. Any future modifications must be clearly identified as changes to the original model.

## License

Lee Dongju's original work in this repository is source-available for non-commercial educational and research use under the custom license in [LICENSE](LICENSE).

Attribution is mandatory. Every permitted use, copy, modification, redistribution, publication, presentation, or derived work must retain and clearly display Lee Dongju's copyright notice, the original repository URL, the contact email, and a clear statement describing any modifications made.

Commercial use requires explicit prior written permission from Lee Dongju. See [COMMERCIAL_LICENSE.md](COMMERCIAL_LICENSE.md).

The TT motor bracket is excluded from the project's custom non-commercial license. The **[TT Gear Motor Mount](https://makerworld.com/en/models/519327-tt-gear-motor-mount)** was created by **[Chief human](https://makerworld.com/en/@Chief_human)** and remains licensed only under the **[Creative Commons Attribution 4.0 International license](https://creativecommons.org/licenses/by/4.0/)**.

Third-party materials retain their original licenses or terms. See [THIRD_PARTY_LICENSES.md](THIRD_PARTY_LICENSES.md).

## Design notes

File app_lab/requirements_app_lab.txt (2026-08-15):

# App Lab runtime dependencies
# Source of truth for: app_lab/Arduino Safety Monitor/python/requirements.txt
#
# DO NOT add training-only packages (torch, torchvision, onnx, ultralytics).
# DO NOT add test-only packages.
# DO NOT request opencv-python or opencv-python-headless here.
#
# Target runtime: CPython 3.13, Linux aarch64 (Arduino App Lab container)
# Generated by: python app_lab/generate_app_lab.py

# Computer vision — camera capture, frame processing, image encoding
# App Lab base image ghcr.io/arduino/app-bricks/python-apps-base:0.12.0
# already provides a working cv2 module from its own aarch64 CPython 3.13
# OpenCV build. The image constrains that local build version, so requesting
# an OpenCV wheel from PyPI makes dependency resolution unsatisfiable.
# Application code should import cv2 normally from the base image.

# Numerical array operations (camera frames, model input tensors)
numpy

# Image preprocessing for HelmetClassifier (PIL.Image.fromarray)
Pillow

# ONNX inference — PersonDetector (ssd_mobilenet_v1) and HelmetClassifier
onnxruntime

# HTTP alert transmission to the remote monitoring server
requests

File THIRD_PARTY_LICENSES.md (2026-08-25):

# Third-Party Licenses

Third-party materials are not covered by the root `LICENSE`. They remain governed by their respective original licenses or terms.

## TT Gear Motor Mount

Component: TT Gear Motor Mount

Creator: Chief human

Source: https://makerworld.com/en/models/519327-tt-gear-motor-mount#profileId-435701

License: Creative Commons Attribution 4.0 International

License URL: https://creativecommons.org/licenses/by/4.0/

Repository path:

- `models/TT+Gear+Motor+Mount.3mf`

The TT Gear Motor Mount is third-party material. It was not created by Lee Dongju, is not owned by Lee Dongju, and is completely excluded from Lee Dongju's custom non-commercial license in the root `LICENSE` file.

The TT Gear Motor Mount remains licensed only under its original Creative Commons Attribution 4.0 International license. CC BY 4.0 permits uses independently of this project's custom non-commercial license.

When the TT Gear Motor Mount or a modified version is redistributed, preserve its original creator, source link, license name, license link, and repository file path. Any modifications to the TT Gear Motor Mount must be clearly identified.

Other third-party software, libraries, datasets, AI models, fonts, assets, or hardware designs remain governed by their respective licenses or terms.

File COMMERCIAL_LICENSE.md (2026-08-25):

# Commercial Licensing

Commercial use of this project is not automatically permitted. Any individual, company, organization, institution, or other party wishing to use any part of Lee Dongju's original project material for a commercial purpose must contact Lee Dongju and receive explicit prior written permission.

Copyright holder: Lee Dongju

Contact email: dozoo0528@gmail.com

Original repository: https://github.com/DongjuLee0528/arduino-safety-monitor

Commercial permission must be granted separately in writing. Silence, repository access, cloning, forking, or public availability must not be interpreted as commercial permission.

## Uses That Require Permission

Commercial use includes, but is not limited to:

- Selling the project or a derived product
- Including it in a paid product or service
- Using it for paid consulting or contract work
- Using it internally to support commercial business operations
- Using it in commercial training, demonstrations, marketing, or promotions
- Manufacturing or distributing commercial hardware based on the project

## Commercial-Use Request Template

Send requests to dozoo0528@gmail.com with the following information:

```text
Requester's name:
Organization:
Intended use:
Project or product description:
Distribution method:
Expected users or customers:
Whether revenue is involved:
Requested permission period:
```

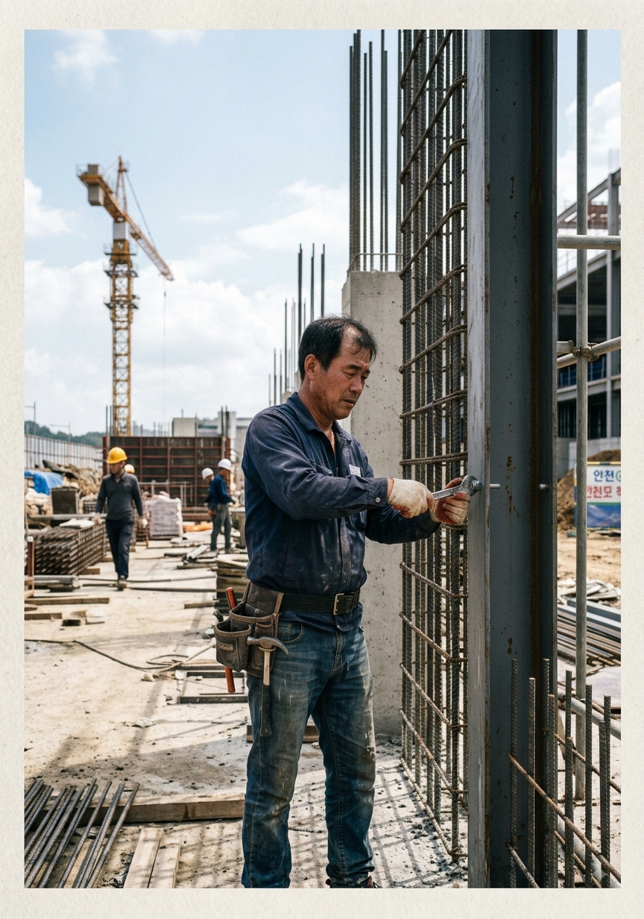
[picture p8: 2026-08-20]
png/no_helmet_person.png

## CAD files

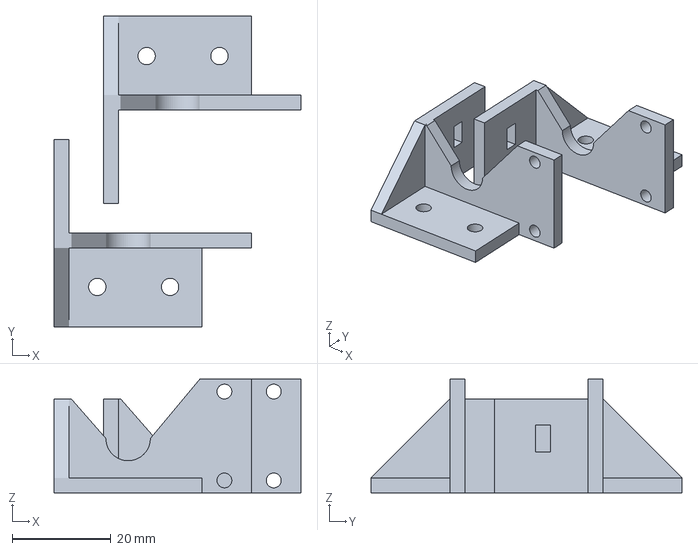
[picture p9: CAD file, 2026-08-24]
models/TT+Gear+Motor+Mount.3mf
50.0 x 63.0 x 23.0 mm

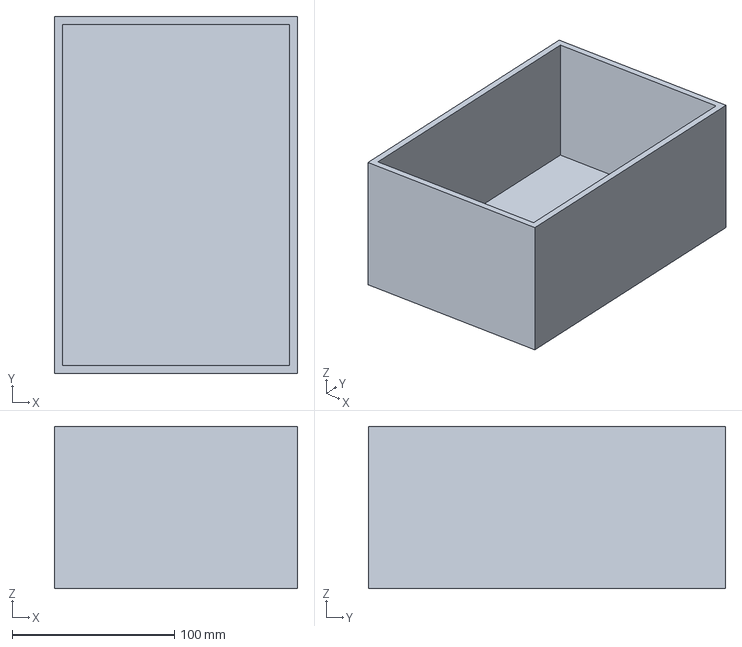
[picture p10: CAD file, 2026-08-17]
models/robot-base-plate.3mf
150.0 x 220.0 x 100.0 mm

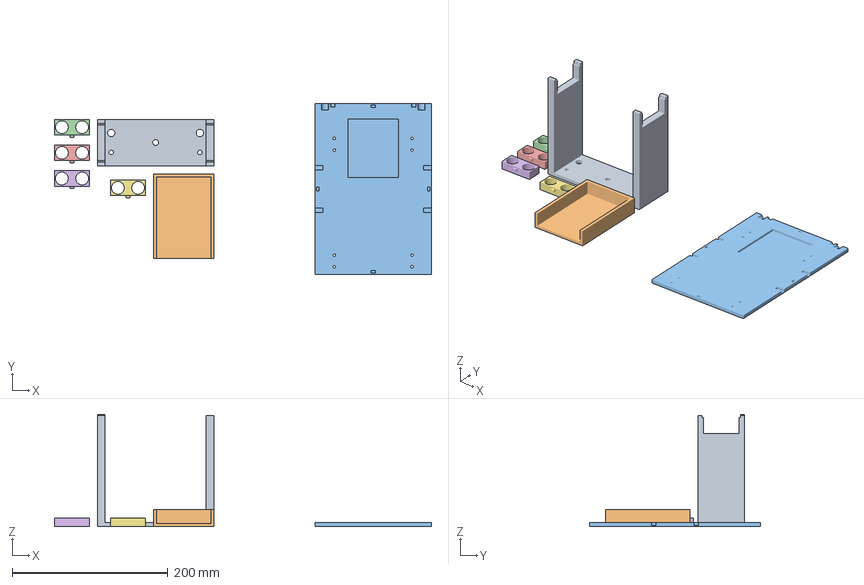
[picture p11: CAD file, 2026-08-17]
models/arduino-uno-q-4wd-robot.3mf
484.7 x 220.0 x 144.0 mm

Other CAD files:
models/arduino-uno-q-4wd-robot.stl

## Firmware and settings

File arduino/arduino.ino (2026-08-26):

/*
 * arduino.ino – Arduino UNO Q Main Sketch
 *
 * Entry point.  Constructs all subsystem objects and delegates every loop
 * iteration to CommunicationManager and RobotController.
 *
 * Communication transport: Arduino UNO Q RouterBridge/RPClite.
 * This is the sole active communication path.
 *
 * Module dependency graph (arrows = "uses"):
 *
 *   arduino.ino
 *     ├─► CommunicationManager  (Bridge RPC command state)
 *     └─► RobotController       (per-loop orchestrator, all motor actions)
 *           ├─► MotorController
 *           ├─► UltrasonicSensor
 *           ├─► NavigationManager
 *           └─► CommunicationManager
 *
 * setup() sequence:
 *   1. Bridge.begin()   – start UNO Q MPU↔MCU RouterBridge IPC
 *   2. motor.begin()    – configure motor pins, enter stopped state
 *   3. comm.begin()     – initialise command/safety state
 *
 * Alert LED and buzzer commands are routed through CommunicationManager RPC handlers.
 * No Wi-Fi.  No network credentials.
 */

#include "Arduino_RouterBridge.h"
#include "config.h"
#include "pins.h"
#include "motor.h"
#include "ultrasonic.h"
#include "navigation.h"
#include "comm.h"
#include "robot_controller.h"

// Left: IN1/IN2 direction pins, right: IN1/IN2 direction pins, then PWM enable pins
MotorController motor(
    MOTOR_LEFT_IN1_PIN,    MOTOR_LEFT_IN2_PIN,
    MOTOR_RIGHT_IN1_PIN,   MOTOR_RIGHT_IN2_PIN,
    MOTOR_LEFT_ENABLE_PIN, MOTOR_RIGHT_ENABLE_PIN
);

// Trigger/echo pin pairs for four HC-SR04 sensors.
// Internal distanceAvailable() / getXxxDistance() index mapping
// (see ultrasonic.h for authoritative definition):
//   0 → front,  1 → right,  2 → rear,  3 → left
UltrasonicSensor ultrasonic(
    ULTRASONIC_FRONT_TRIGGER_PIN, ULTRASONIC_FRONT_ECHO_PIN,
    ULTRASONIC_REAR_TRIGGER_PIN,  ULTRASONIC_REAR_ECHO_PIN,
    ULTRASONIC_LEFT_TRIGGER_PIN,  ULTRASONIC_LEFT_ECHO_PIN,
    ULTRASONIC_RIGHT_TRIGGER_PIN, ULTRASONIC_RIGHT_ECHO_PIN
);

CommunicationManager comm;                       // Handles Bridge RPC command state
RobotController      robot(&motor, &ultrasonic, &comm); // Orchestrates all motion logic

// RPC wrapper functions keep Bridge.provide_safe signatures simple and explicit.
String asm_ping() {
    return comm.rpcPing();
}

String asm_led(String value) {
    return comm.rpcLed(value);
}

String asm_buzzer(String state) {
    return comm.rpcBuzzer(state);
}

String asm_motor(String direction, int speed) {
    return comm.rpcMotor(direction, speed);
}

String asm_mode(String value) {
    return comm.rpcMode(value);
}

String asm_safe_reset() {
    return comm.rpcSafeReset();
}

String asm_control_tick() {
    return comm.rpcControlTick();
}

String asm_manual_hold() {
    return comm.rpcManualHold();
}

String asm_status() {
    return comm.rpcStatus(
        motor.getMovement(),
        motor.getSpeed(),
        ultrasonic.distanceAvailable(0),
        ultrasonic.getFrontDistance(),
        ultrasonic.distanceAvailable(2),
        ultrasonic.getBackDistance(),
        ultrasonic.distanceAvailable(3),
        ultrasonic.getLeftDistance(),
        ultrasonic.distanceAvailable(1),
        ultrasonic.getRightDistance()
    );
}

String asm_ultrasonic_diag() {
    if (comm.getMode() != MODE_MANUAL) {
        return "{\"type\":\"error\",\"error\":\"DIAG_REQUIRES_MANUAL\"}";
    }
    ultrasonic.measureAllOnce();
    return comm.rpcUltrasonicDiagnostic(
        ultrasonic.distanceAvailable(0),
        ultrasonic.getFrontDistance(),
        ultrasonic.distanceAvailable(2),
        ultrasonic.getBackDistance(),
        ultrasonic.distanceAvailable(3),
        ultrasonic.getLeftDistance(),
        ultrasonic.distanceAvailable(1),
        ultrasonic.getRightDistance()
    );
}

String asm_buzzer_tone_diag(int frequency_hz, int duration_ms) {
    if (comm.getMode() != MODE_MANUAL) {
        return "{\"type\":\"error\",\"error\":\"DIAG_REQUIRES_MANUAL\"}";
    }
    return comm.rpcBuzzerToneDiag(frequency_hz, duration_ms);
}

void setup() {
    Bridge.begin();
    Bridge.provide_safe("asm_ping", asm_ping);
    Bridge.provide_safe("asm_led", asm_led);
    Bridge.provide_safe("asm_buzzer", asm_buzzer);
    Bridge.provide_safe("asm_motor", asm_motor);
    Bridge.provide_safe("asm_mode", asm_mode);
    Bridge.provide_safe("asm_safe_reset", asm_safe_reset);
    Bridge.provide_safe("asm_control_tick", asm_control_tick);
    Bridge.provide_safe("asm_manual_hold", asm_manual_hold);
    Bridge.provide_safe("asm_status", asm_status);
    Bridge.provide_safe("asm_ultrasonic_diag", asm_ultrasonic_diag);
    Bridge.provide_safe("asm_buzzer_tone_diag", asm_buzzer_tone_diag);

    motor.begin();                  // Configure motor GPIO pins and enter stopped state
    ultrasonic.begin();             // Configure ultrasonic sensor GPIO pins
    comm.begin();                   // Initialise command/safety state
}

void loop() {
    comm.update();          // Update command timeout, motion lease, and warning state
    robot.update();         // Execute one control cycle (obstacle check, motor commands)
    delay(LOOP_DELAY_MS);   // Fixed loop rate defined in config.h
}

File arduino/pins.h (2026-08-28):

/*
 * pins.h – Hardware Pin Assignments for Arduino UNO Q Robot
 *
 * Defines all GPIO pin numbers for:
 *   - L298N Motor Driver (direction + PWM)
 *   - HC-SR04 Ultrasonic sensors ×4
 *
 * L298N wiring notes:
 *   - Remove ENA and ENB jumpers; PWM speed control is applied via ENA/ENB.
 *   - OUT1/OUT2 drive the left-front and left-rear TT motors (left channel).
 *   - OUT3/OUT4 drive the right-front and right-rear TT motors (right channel).
 *   - All grounds (Arduino, L298N, battery) must share a common ground.
 *   - HC-SR04 sensors are powered from the 5 V bus.
 *   - A0–A3 are used as digital GPIO (no ADC reads on these pins).
 *
 * Reserved pins (do not assign):
 *   D0  – UART RX
 *   D1  – UART TX
 *   D3  – ALERT_LED_PIN
 *   A4  – I2C SDA
 *   A5  – I2C SCL
 *
 * Active pin uniqueness table:
 *   D2  – MOTOR_LEFT_IN1_PIN
 *   D4  – MOTOR_LEFT_IN2_PIN
 *   D5  – MOTOR_LEFT_ENABLE_PIN   (PWM)
 *   D6  – MOTOR_RIGHT_ENABLE_PIN  (PWM)
 *   D7  – MOTOR_RIGHT_IN1_PIN
 *   D8  – MOTOR_RIGHT_IN2_PIN
 *   D9  – ULTRASONIC_FRONT_TRIGGER_PIN
 *   D10 – ULTRASONIC_FRONT_ECHO_PIN
 *   D11 – ULTRASONIC_REAR_TRIGGER_PIN
 *   D12 – ULTRASONIC_REAR_ECHO_PIN
 *   D13 – BUZZER_DIAG_PIN         (diagnostic/test tone only)
 *   A0  – ULTRASONIC_LEFT_TRIGGER_PIN  (digital GPIO)
 *   A1  – ULTRASONIC_LEFT_ECHO_PIN     (digital GPIO)
 *   A2  – ULTRASONIC_RIGHT_TRIGGER_PIN (digital GPIO)
 *   A3  – ULTRASONIC_RIGHT_ECHO_PIN    (digital GPIO)
 */

#ifndef PINS_H
#define PINS_H

// ---------------------------------------------------------------------------
// L298N Motor Driver
// ---------------------------------------------------------------------------
#define MOTOR_LEFT_ENABLE_PIN   5    // ENA – left  channel PWM speed (PWM-capable)
#define MOTOR_LEFT_IN1_PIN      2    // IN1 – left  channel direction A
#define MOTOR_LEFT_IN2_PIN      4    // IN2 – left  channel direction B
#define MOTOR_RIGHT_ENABLE_PIN  6    // ENB – right channel PWM speed (PWM-capable)
#define MOTOR_RIGHT_IN1_PIN     7    // IN3 – right channel direction A
#define MOTOR_RIGHT_IN2_PIN     8    // IN4 – right channel direction B
#define ALERT_LED_PIN           3    // D3 – red helmet-warning LED control output (PWM-capable)
#define BUZZER_DIAG_PIN         13   // D13 – buzzer diagnostic signal output (active-HIGH, temporary diagnostic use)

// ---------------------------------------------------------------------------
// HC-SR04 Ultrasonic Sensors
// A0–A3 are used as digital GPIO; no ADC reads occur on these pins.
// ---------------------------------------------------------------------------
#define ULTRASONIC_FRONT_TRIGGER_PIN   9    // Front sensor trigger
#define ULTRASONIC_FRONT_ECHO_PIN      10   // Front sensor echo
#define ULTRASONIC_REAR_TRIGGER_PIN    11   // Rear  sensor trigger
#define ULTRASONIC_REAR_ECHO_PIN       12   // Rear  sensor echo
#define ULTRASONIC_LEFT_TRIGGER_PIN    A0   // Left  sensor trigger (analog pin as digital)
#define ULTRASONIC_LEFT_ECHO_PIN       A1   // Left  sensor echo   (analog pin as digital)
#define ULTRASONIC_RIGHT_TRIGGER_PIN   A2   // Right sensor trigger (analog pin as digital)
#define ULTRASONIC_RIGHT_ECHO_PIN      A3   // Right sensor echo   (analog pin as digital)
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

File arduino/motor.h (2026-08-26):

/*
 * motor.h – MotorController for L298N Dual H-Bridge
 *
 * Responsibility:
 *   Drives four TT DC motors through an L298N motor driver.
 *   Provides a clean movement API; all pin numbers and speed values
 *   are kept inside this class or in config.h.
 *
 * Design notes:
 *   - Constructor stores pin numbers only.  No GPIO writes occur there,
 *     because Arduino global constructors run before the hardware is ready.
 *   - Call begin() inside setup() to configure pins and enter a known stop.
 *   - setSpeed() clamps its argument to [MOTOR_SPEED_MIN, MOTOR_SPEED_MAX]
 *     and stores the result; subsequent movement calls use the stored speed.
 *   - All analogWrite() calls use the internally stored, clamped speed value.
 *   - left() and right() are aliases for turnLeft() and turnRight() to satisfy
 *     the required API surface.
 *   - LEFT_MOTOR_REVERSED in config.h corrects mirrored left-channel polarity.
 *
 * Public API:
 *   begin()       – configure GPIO, enter stopped state
 *   forward()     – both motors forward at stored speed
 *   backward()    – both motors backward at stored speed
 *   left()        – counter-clockwise point turn at stored speed
 *   right()       – clockwise point turn at stored speed
 *   stop()        – brake (both H-bridge sides HIGH, PWM = 0)
 *   setSpeed(v)   – clamp v and store as current speed
 *   getSpeed()    – return current stored speed
 */

#ifndef MOTOR_H
#define MOTOR_H

#include "config.h"

class MotorController {
private:
    int _lf, _lb, _rf, _rb;  // L298N direction control pins: left-forward, left-backward, right-forward, right-backward
    int _lpwm, _rpwm;         // L298N PWM enable pins: ENA (left side) and ENB (right side)
    int _speed;               // Active PWM duty cycle [MOTOR_SPEED_MIN, MOTOR_SPEED_MAX]
    const char* _movement;      // Last commanded movement string exposed through rpcStatus()

    // Clamp v to [MOTOR_SPEED_MIN, MOTOR_SPEED_MAX] to prevent invalid PWM values
    int clamp(int v) const {
        if (v < MOTOR_SPEED_MIN) return MOTOR_SPEED_MIN;
        if (v > MOTOR_SPEED_MAX) return MOTOR_SPEED_MAX;
        return v;
    }

    // Write the current stored speed value to both PWM enable pins simultaneously
    void applyPWM() {
        analogWrite(_lpwm, _speed);  // Left side PWM
        analogWrite(_rpwm, _speed);  // Right side PWM
    }

    void writeSide(int forwardPin, int backwardPin, bool forward, bool reversed) {
        bool driveForward = reversed ? !forward : forward;
        // L298N direction pins are complementary for drive mode.
        digitalWrite(forwardPin,  driveForward ? HIGH : LOW);
        digitalWrite(backwardPin, driveForward ? LOW : HIGH);
    }

public:
    /*
     * Constructor – stores pin numbers only.
     * Does NOT call pinMode() or digitalWrite().
     */
    MotorController(int lf, int lb, int rf, int rb, int lpwm, int rpwm)
        : _lf(lf), _lb(lb), _rf(rf), _rb(rb),
          _lpwm(lpwm), _rpwm(rpwm),
          _speed(MOTOR_SPEED_DEFAULT),
          _movement("stopped") {}

    /*
     * begin() – call once from setup().
     * Configures all pins as OUTPUT and enters a known stopped state.
     */
    void begin() {
        pinMode(_lf,   OUTPUT);
        pinMode(_lb,   OUTPUT);
        pinMode(_rf,   OUTPUT);
        pinMode(_rb,   OUTPUT);
        pinMode(_lpwm, OUTPUT);
        pinMode(_rpwm, OUTPUT);
        stop();
    }

    /*
     * setSpeed() – clamp v to [MOTOR_SPEED_MIN, MOTOR_SPEED_MAX] and store.
     * Does not change current direction.
     */
    void setSpeed(int v) {
        _speed = clamp(v);
    }

    int getSpeed() const {
        return _speed;
    }

    const char* getMovement() const {
        return _movement;
    }

    /* forward() – drive both sides in the forward direction at the stored speed. */
    void forward() {
        _movement = "forward";
        writeSide(_lf, _lb, true,  LEFT_MOTOR_REVERSED);
        writeSide(_rf, _rb, true,  false);
        applyPWM();
    }

    /* backward() – drive both sides in reverse at the stored speed. */
    void backward() {
        _movement = "backward";
        writeSide(_lf, _lb, false, LEFT_MOTOR_REVERSED);
        writeSide(_rf, _rb, false, false);
        applyPWM();
    }

    /*
     * turnLeft() – counter-clockwise point turn.
     * Left motor reverses, right motor drives forward.
     */
    void turnLeft() {
        _movement = "left";
        writeSide(_lf, _lb, false, LEFT_MOTOR_REVERSED);
        writeSide(_rf, _rb, true,  false);
        applyPWM();
    }

    /*
     * turnRight() – clockwise point turn.
     * Left motor drives forward, right motor reverses.
     */
    void turnRight() {
        _movement = "right";
        writeSide(_lf, _lb, true,  LEFT_MOTOR_REVERSED);
        writeSide(_rf, _rb, false, false);
        applyPWM();
    }

    void left()  { turnLeft();  }  // Public alias for turnLeft() – satisfies the external API contract
    void right() { turnRight(); }  // Public alias for turnRight() – satisfies the external API contract

    /*
     * stop() – brake mode: both H-bridge sides HIGH, PWM zero.
     * Safe to call before begin() (pins may not be configured yet in that case,
     * but the method is idempotent after begin()).
     */
    void stop() {
        _movement = "stopped";
        _speed = MOTOR_SPEED_MIN;
        digitalWrite(_lf,  HIGH);
        digitalWrite(_lb,  HIGH);
        digitalWrite(_rf,  HIGH);
        digitalWrite(_rb,  HIGH);
        analogWrite(_lpwm, MOTOR_SPEED_MIN);
        analogWrite(_rpwm, MOTOR_SPEED_MIN);
    }
};

#endif

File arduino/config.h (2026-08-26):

/*
 * config.h – Robot Configuration Constants
 *
 * Single source of truth for firmware tuneable values.
 * Hardware calibration and safety timing constants belong here.
 *
 * Sections:
 *   1. Motor control
 *   2. Timing
 *   3. Ultrasonic sensors
 *   4. Navigation / obstacle avoidance
 *   5. Buzzer diagnostic
 *   6. Communication
 */

#ifndef CONFIG_H
#define CONFIG_H

// ---------------------------------------------------------------------------
// 1. Motor control
// ---------------------------------------------------------------------------
#define MOTOR_SPEED_MIN        0     // Minimum valid PWM value
#define MOTOR_SPEED_MAX        255   // Maximum valid PWM value
#define MOTOR_SPEED_DEFAULT    150   // Default PWM speed used by setSpeed()
#define CRUISE_SPEED           150   // PWM for autonomous forward cruising
#define OBSTACLE_AVOID_SPEED   150   // PWM for obstacle-avoidance manoeuvres
#define TURN_SPEED             200   // PWM for point turns (left / right)
#define LEFT_MOTOR_REVERSED    true  // Invert left channel polarity for mirrored motor mounting
#define HELMET_WARNING_BUZZER_DURATION_MS 5000  // Helmet warning buzzer/blink duration
#define LED_BLINK_INTERVAL_MS  250   // Helmet warning LED toggle interval

// ---------------------------------------------------------------------------
// 2. Timing
// ---------------------------------------------------------------------------
#define LOOP_DELAY_MS          10    // Main loop delay in ms (≈100 Hz)

// ---------------------------------------------------------------------------
// 3. Ultrasonic sensors
// ---------------------------------------------------------------------------
#define ULTRASONIC_TIMEOUT_US  30000 // pulseIn() timeout in µs (≈5 m max range)
#define ULTRASONIC_SAMPLES     3     // Rolling-average window size
#define ULTRASONIC_INTERVAL_MS 50    // Minimum ms between consecutive readings
#define MAX_SENSOR_RANGE_CM    300.0 // Value returned when no valid reading exists

// ---------------------------------------------------------------------------
// 4. Navigation / obstacle avoidance
// ---------------------------------------------------------------------------
#define OBSTACLE_THRESHOLD_CM  25.0  // Distance (cm) at which a sensor fires "blocked"
#define SENSOR_STALE_TIMEOUT_MS 1000 // Max age (ms) of a valid reading; older readings are treated as unavailable

// Motion lease – separate from the serial connection keepalive.
// Only the Python main control loop may renew this; generic ping cannot.
// If no control_tick arrives within this window, CommunicationManager
// latches a durable STOP before processing any further commands.
#define MOTION_LEASE_TIMEOUT_MS 1000
#define MANUAL_HOLD_TIMEOUT_MS  500  // Max ms a manual movement may continue without a manual_hold refresh

// ---------------------------------------------------------------------------
// 5. Buzzer
// ---------------------------------------------------------------------------
#define BUZZER_WARN_FREQ_HZ            2000  // Production warning tone frequency (Hz)
#define BUZZER_WARN_HALF_PERIOD_MS     500   // Warning tone on/off half-period (ms)
#define BUZZER_TEST_DURATION_MS        250   // BZR test beep duration (ms)
#define BUZZER_DIAG_DURATION_MIN_MS    100   // Minimum buzzer diagnostic pulse duration (ms)
#define BUZZER_DIAG_DURATION_MAX_MS    1000  // Maximum buzzer diagnostic pulse duration (ms)
#define BUZZER_TONE_DIAG_FREQUENCY_MIN_HZ  500   // Minimum buzzer tone diagnostic frequency (Hz)
#define BUZZER_TONE_DIAG_FREQUENCY_MAX_HZ  5000  // Maximum buzzer tone diagnostic frequency (Hz)

// ---------------------------------------------------------------------------
// 6. Communication – UNO Q RouterBridge / BridgeRPC command protocol
// ---------------------------------------------------------------------------
#define COMM_SEND_INTERVAL_MS  100     // Interval between outgoing telemetry messages (ms)

// If no valid Bridge command is received from the host within this interval
// (ms), CommunicationManager declares the connection lost (isConnected() →
// false).
// RobotController then stops motors and forces MANUAL mode.
// The robot resumes only after a new valid command is received.
#define COMMAND_TIMEOUT_MS     2000

#endif

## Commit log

2026-05-10 chore: add .gitignore for Python, Arduino, and macOS
2026-05-17 feat: implement camera.py for real-time frame capture
2026-05-17 docs: add comments to camera.py
2026-05-23 feat: implement motor.h for L298N PWM motor control
2026-05-24 feat: implement ultrasonic.h for obstacle detection and avoidance
    [ultrasonic.h]
2026-05-25 feat: complete Arduino and MPU implementation with system integration
2026-06-08 refactor: eliminate hardcoding and unify Arduino-MPU interface
2026-07-23 Centralize camera configuration for UNO Q runtime
2026-07-23 feat: add autonomous cruise and resume after obstacle avoidance
    [config.h]
2026-07-25 fix: validate Arduino RPC commands
2026-07-25 fix: stop motors on mode changes and block manual commands in auto
2026-07-27 feat: add motor controller, ultrasonic manager and navigation framework
2026-07-27 fix: harden Arduino motor, sensor, and command control
2026-07-28 refactor: finalize UNO R4 motor and ultrasonic pin map
2026-07-28 feat: add Arduino UNO R4 Wi-Fi robot control system
2026-08-01 refactor: migrate communication architecture to Arduino UNO Q
2026-08-01 fix: improve runtime robustness and hardware readiness
    [test_phase2_fixes.py]
2026-08-01 docs: update README for Arduino UNO Q architecture
2026-08-03 fix: enforce stop priority and validated worker state
    [comm.h]
2026-08-03 fix: finalize hardware bench testing readiness
    [comm.h]
2026-08-03 fix: harden MCU stop safety and ultrasonic freshness
    [comm.h]
2026-08-03 fix: add MCU motion lease watchdog
    [comm.h]
2026-08-03 fix: clear motion lease on manual mode and send stop on shutdown
    [comm.h]
2026-08-05 feat: add no-helmet warning state with led blink and stop timer
2026-08-05 fix: finalize helmet warning shutdown safety
    [comm.h, test_helmet_warning.py, test_main_integration.py]
2026-08-08 feat: add self-contained Arduino App Lab packaging
2026-08-10 fix: enable hardware-free mode for App Lab development
    [test_app_lab_packaging.py]
2026-08-11 feat: redesign App Lab dashboard with responsive layout
    [test_app_lab_packaging.py]
2026-08-11 fix: make camera cleanup idempotent
2026-08-13 fix: improve dashboard viewport utilization
    [test_app_lab_packaging.py]
2026-08-13 fix: use App Lab provided OpenCV runtime
    [test_app_lab_packaging.py]
2026-08-16 Fix App Lab ESTOP best-effort safety RPC handling
    [test_app_lab_packaging.py]
2026-08-17 feat: add 3D modeling files
    [arduino-uno-q-4wd-robot.3mf]
2026-08-17 feat: add robot chassis 3D model
    [robot-base-plate.3mf]
2026-08-18 Add manual-mode ultrasonic diagnostic RPC
2026-08-18 Add left motor polarity inversion config
2026-08-19 Add D13 buzzer diagnostic RPC
    [arduino.ino]
2026-08-20 feat: integrate buzzer with confirmed helmet warnings
    [arduino.ino, comm.h]
2026-08-20 fix: improve manual control safety and alert handling
    [arduino.ino, comm.h, config.h]
2026-08-20 fix(ai): repair evaluator entrypoint and add guarded model comparison
    [test_helmet_classifier_contract.py, test_helmet_dataset_loader.py, test_training_pipeline.py]
2026-08-21 fix(navigation): adjust obstacle threshold to 25 cm
    [config.h]
2026-08-23 docs: update README with BOM, power architecture, and project images
2026-08-24 docs: add 3D models and motor mount attribution
    [arduino-uno-q-4wd-robot.3mf]
2026-08-25 Add comments for control and dashboard flow
